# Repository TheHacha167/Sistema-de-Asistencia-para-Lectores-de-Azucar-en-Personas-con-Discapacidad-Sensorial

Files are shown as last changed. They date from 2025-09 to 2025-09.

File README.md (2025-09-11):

# TFG — Sistema de Asistencia para Lectores de Glucosa en Personas con Discapacidad Sensorial

Proyecto desarrollado como parte de mi **Trabajo Fin de Grado (TFG)**.  
**El proyecto ha sido bautizado como _Gluco Alert_.**  
El sistema detecta vibraciones anómalas en un lector de glucosa y notifica al cuidador mediante aviso local (luz y vibración) y remoto (llamadas/SMS).

---

## ÍNDICE

1. [Resumen](#1-resumen)  
2. [Características principales](#2-características-principales)  
3. [Hardware (BOM) y conexiones](#3-hardware-bom-y-conexiones)  
4. [Flujo de funcionamiento](#4-flujo-de-funcionamiento)  
5. [Control remoto (SMS / DTMF)](#5-control-remoto-sms--dtmf)  
6. [Compilación, flasheo y monitor](#6-compilación-flasheo-y-monitor)  
7. [Estructura de ficheros en la microSD](#7-estructura-de-ficheros-en-la-microsd)  
8. [Pruebas recomendadas](#8-pruebas-recomendadas)  
9. [Solución de problemas (Troubleshooting)](#9-solución-de-problemas-troubleshooting)  
10. [Seguridad eléctrica](#10-seguridad-eléctrica)  
11. [Licencia y citación](#11-licencia-y-citación)  
12. [Agradecimientos](#12-agradecimientos)  
13. [Vídeo de demostración (placeholder)](#13-vídeo-de-demostración-placeholder)  

---

## 1) RESUMEN

El sistema se basa en un **ESP32-C6** con firmware ESP-IDF y un módem GSM.  
Un sensor de vibración (salida digital) se procesa con antirruido (contador de ≥3 golpes en una ventana de 800 ms).  
Al dispararse la alerta, se activan tres relés (dos motores vibradores y una luz), se abre una ventana de atención de 30 s (botón físico), y si no se atiende, se realizan llamadas a números preconfigurados, reproduciendo un aviso por I2S desde la tarjeta microSD.  
Un pin de “armado” detecta la presencia del lector. Además, existe control remoto básico por SMS (con clave) y soporte DTMF en llamada.

---

## 2) CARACTERÍSTICAS PRINCIPALES

- Detección robusta de vibración con umbral configurable (≥3 en 800 ms).  
- Aviso local: dos motores vibradores + luz (a través de relés).  
- Ventana de atención: 30 s con botón físico (enciende luz de atención).  
- Llamadas automáticas a dos números, con reproducción de mensaje de voz por I2S/SD.  
- Entrada “ARM” para activar el sistema cuando el lector esté presente.  
- Control y diagnóstico por SMS (clave por defecto `0000`).  
- Prueba remota de sistema (activa relés durante 10 s, sin llamadas).  
- Diseño eléctrico con tres raíles: 5 V (lógica), 4,3 V (GSM), 12 V (motores).

---

## 3) HARDWARE (BOM) Y CONEXIONES

**Placa principal:**
- ESP32-C6-DevKitC-1

**Comunicación:**
- Módem GSM (SIM800/SIM8xx) alimentado a 4,3 V  
  (con >1000 µF cerca del VCC)

**Almacenamiento / audio:**
- Módulo microSD a 5 V (con regulador y adaptación de nivel)  
- DAC I2S integrado del ESP32-C6 (WAV mono 16-bit desde SD)

**Actuadores:**
- Módulo de 4 relés (LOW-trigger, se usan 3)  
- 2 motores vibradores (12 V conmutados por relé)  
- Luz / lamparita (red eléctrica conmutada por relé)

**Sensores y E/S locales:**
- Sensor de vibración Piezoeléctrico (salida digital, 5 V)  
- Entrada ARM  
- Botón de atención

**Alimentación:**
- 5 V → ESP32, módulo SD, módulo relés  
- 4,3 V → Módem GSM  
- 12 V → Motores vibradores  
- Condensadores: 1000 µF por raíl + 100 µF de desacoplo  
- Masa común en punto estrella cerca de GND del ESP32  
- Cableado corto para SPI y UART

**Pinout ESP32-C6:**

| Función | GPIO |
|---|---|
| Sensor vibración (D0) | GPIO2 |
| ARM | GPIO3 |
| Botón atención | GPIO4 |
| Relé Vib1 | GPIO8 |
| Relé Vib2 | GPIO10 |
| Relé Luz | GPIO11 |
| Relé reservado | GPIO12 |
| UART1 TX (SIM RX) | GPIO7 |
| UART1 RX (SIM TX) | GPIO6 |
| SD Card CS | GPIO5 |
| SD SCK | GPIO18 |
| SD MOSI | GPIO19 |
| SD MISO | GPIO21 |

**Notas:**
- PWRKEY del SIM a GND durante 1–2 s al encender  
- DTR a GND para evitar sleep  
- SPI: si es largo, reducir frecuencia a 4–10 MHz  
- Verificar niveles de MISO del módulo SD

---

## 4) FLUJO DE FUNCIONAMIENTO

1. **Arranque:** Inicialización de GPIO, SD, I2S, UART, timers  
2. **Lectura de ARM:** IDLE (ausente) / ARMED (presente)  
3. En estado ARMED:
   - Detección de ≥3 golpes → ALARM  
   - ALARM: activa vibradores y luz, inicia temporizador de 30 s  
   - Si se pulsa el botón: se atiende → relés OFF, colgado de módem  
   - Si NO se atiende: pasa a CALLING
4. **CALLING:**
   - Realiza llamadas a NUM1 y NUM2, reproduce mensaje por I2S/SD  
   - Vib OFF, luz queda ON  
   - Luego retorna a IDLE/ARMED según ARM

---

## 5) CONTROL REMOTO (SMS / DTMF)

**Por SMS (requiere clave, ej. `0000 prueba`)**

Comandos disponibles:
- Ayuda / menú  
- Prueba de relés (10 s)  
- Consulta de estado  
- Prueba de SMS/llamadas  
- Cancelar alerta  
- Reinicio del sistema  
- Cambio de clave

**Por DTMF (durante llamada):**
- Recepción de dígitos  
- Ejecución de acciones básicas con confirmación por audio  
- Archivos `/sdcard/0.wav` … `/sdcard/9.wav` opcionales

---

## 6) COMPILACIÓN, FLASHEO Y MONITOR

**Entorno recomendado:** PlatformIO + ESP-IDF (ESP32-C6)

```bash
# Compilar
pio run

# Flashear
pio run -t upload

# Monitor serie
pio device monitor -b 115200
```

**Configuración importante:**

- Velocidad del monitor: `115200` baudios
- Tamaño de la flash: debe coincidir con la configuración del módulo (ej. 2 MB si así está indicado en `sdkconfig` o `sdkconfig.defaults`)
- Mensajes del driver I2S tipo “legacy”: son normales, el sistema usa actualmente la API antigua y está pendiente de migrar a `i2s_std`

---

## 7) ESTRUCTURA DE FICHEROS EN LA MICROSD

- `/sdcard/ALERT.WAV` → mensaje de alerta que se reproduce durante las llamadas
- `/sdcard/0.WAV` a `/sdcard/9.WAV` → (opcional) locuciones o tonos DTMF para interacción en llamada

**Recomendaciones técnicas:**

- Formato: WAV PCM, 16-bit, mono, entre 8 y 16 kHz
- Nombres de archivos en mayúsculas
- Formato del sistema de archivos: FAT/FAT32

---

## 8) PRUEBAS RECOMENDADAS

Se recomienda realizar pruebas en las siguientes condiciones:

- Vibración real del lector de glucosa (simular golpes controlados)
- Verificación de la detección de ≥3 golpes en 800 ms
- Prueba de activación y cancelación con el botón físico
- Ensayo de ciclo completo: vibración → alerta → llamadas → reproducción de audio → vuelta a reposo
- Envío de comandos SMS (clave, prueba, consulta de estado)
- Prueba con diferentes niveles de batería / voltaje
- Control DTMF (si está habilitado)

---

## 9) SOLUCIÓN DE PROBLEMAS (TROUBLESHOOTING)

**SD Card:**

- Errores `0x107`, `0x108`, `0x109`:
  - Verifica alimentación 5 V y masa común
  - Chequea conexiones SPI (CS, SCK, MOSI, MISO)
  - Usa cableado corto
  - Reduce la frecuencia SPI (4–10 MHz)
  - Cambia la tarjeta por otra y reformatea en FAT

**Módem GSM:**

- No responde:
  - Alimentación de 4,3 V estable con picos de corriente disponibles
  - Condensador ≥1000 µF cerca del VCC
  - TX y RX correctamente conectados (no cruzados)
  - PWRKEY a GND 1–2 s al arrancar
  - Antena conectada, buena cobertura
  - SIM sin PIN activo

**Relés:**

- No activan:
  - Asegúrate de que el módulo es **LOW-trigger**
  - Si es **HIGH-trigger**, invierte la lógica en el firmware

**Vibración:**

- Falsos positivos:
  - Ajustar sensibilidad del sensor (potenciómetro)
  - Alimentar con 5 V estables
  - Separar el cableado de potencia de la señal
  - Evitar ruidos mecánicos cercanos

---

## 10) SEGURIDAD ELÉCTRICA

- Para cargas a 230 V:
  - Siempre conmutar la **fase (L)**, no el neutro (N)
  - Usar borneras, conectores y aislamientos apropiados
  - Mantener distancias de seguridad (fugas, aislamiento)
  - Instalar en caja cerrada sin partes accesibles a tensión de red
  - Revisión final por **personal cualificado**

---

## 11) LICENCIA Y CITACIÓN

Este proyecto se publica bajo la siguiente licencia:

**Creative Commons — Atribución-NoComercial-SinDerivadas 4.0 Internacional**  
[CC BY-NC-ND 4.0](https://creativecommons.org/licenses/by-nc-nd/4.0/deed.es)

- Puedes compartir el trabajo **citando al autor**
- No se permite el uso **comercial**
- No se permiten **obras derivadas**

---

## 13) VÍDEO DE DEMOSTRACIÓN (PLACEHOLDER)

Enlace al vídeo: **[pendiente de subir]**

---

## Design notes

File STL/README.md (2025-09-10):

# Glauco Alert — STL

Este directorio contiene los modelos 3D del proyecto **Glauco Alert** (carcasa, base, soportes y accesorios). Las piezas están pensadas para alojar un **lector FreeStyle Libre 2** de Abbott y los elementos mecánicos/electrónicos del sistema.

## Impresora y material
- **Impresora:** Artillery **Genius Pro**
- **Filamento:** PLA HD Winkle 1.75 mm **Malva** (1 kg)  
  <https://winkle.shop/producto/filamento-pla-hd-winkle-175-mm-1-kg-malva/>

> Si quieres replicar exactamente mi resultado, ese es el mismo filamento que utilicé.

## Perfil de impresión (Cura)
- **Perfil base:** Ajustes predeterminados de Cura para Genius Pro
- **Altura de capa:** **0.20 mm**
- **Infill:** **15%** patrón **Gyroid**
- **Soportes:** **Orgánicos** y **autogenerados** (solo donde haga falta)
- **Perímetros/Top/Bottom:** valores por defecto del perfil
- **Boquilla:** 0.4 mm (estándar)
- **Adhesión:** falda o balsa según necesidad de tu cama

> Los tiempos dependen de tu máquina y parámetros. A mí, imprimir **todo el conjunto** me llevó **aprox. 3 días** en total.

## Piezas incluidas (resumen)
- **Base** (módulos/apoyos)
- **Funda del lector**
- **Soporte del botón**
- **Soportes de motores de vibración** (x2 de cada uno)

> Las tolerancias están pensadas para PLA. Si tu impresora tiende a cerrar agujeros o encoger encajes, considera **ajustar flujo** o **escala ±1–2%**.

## Consejos de impresión
- Coloca las piezas **con la cara más plana hacia la cama** para minimizar soportes.
- Activa **árboles orgánicos** solo en salientes críticos (ahorra tiempo y material).
- Verifica **tolerancias en seco** antes de atornillar o montar electrónica.
- Para piezas de esfuerzo (soportes de motor), usa **más paredes** si lo ves necesario.

## Licencia
Estos modelos se publican bajo **CC BY-NC-ND 4.0**: puedes compartir citando al autor, **sin** uso comercial **ni** obras derivadas.

---
*Proyecto TFG — Glauco Alert.*

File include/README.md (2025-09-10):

Este directorio contiene los archivos de cabecera (header files) del proyecto. A continuación se describe el propósito de cada archivo y cómo configurar `secrets.h`.

## Archivos en este directorio

- **audio.h**  
  Declaraciones y definiciones relacionadas con el manejo de audio en el sistema.

- **dtmf.h**  
  Funciones y macros para el procesamiento de tonos DTMF (Dual-tone multi-frequency).

- **modem.h**  
  Interfaces y definiciones para la comunicación con el módem.

- **secrets.h**  
  Archivo destinado a almacenar información sensible como claves, tokens o contraseñas necesarias para el funcionamiento del sistema. Este archivo **no debe ser subido al repositorio** para proteger la información confidencial.

- **sms.h**  
  Declaraciones para el envío y recepción de mensajes SMS.

## Configuración de `secrets.h`

Para configurar `secrets.h`, crea el archivo si no existe y define en él las constantes o variables necesarias para tu entorno. Por ejemplo:

```c
// secrets.h (ejemplo)
#pragma once
#define NUM1 "1234567890"
#define NUM2 "0987654321"

```

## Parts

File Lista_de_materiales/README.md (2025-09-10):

# Lista de materiales (BOM) — Gluco Alert

Este documento recoge el *Bill of Materials* del proyecto **Glauco Alert** (TFG). Incluye los componentes principales, su función en el sistema y el motivo de elección, así como materiales recomendados adicionales para el montaje seguro y ordenado.

> **Nota:** La selección está orientada a un montaje doméstico con **ESP32‑C6 + módem GSM** y actuación por **relés** (motores de vibración y luz). Ajusta cantidades y referencias exactas según tu diseño final.

---

## 1) Componentes principales

| Componente | Modelo / referencia | Función en el sistema | Motivo de elección |
|---|---|---|---|
| **ESP32‑C6** | DevKitC‑1 (u otro compatible) | Unidad de procesamiento principal | MCU con Wi‑Fi/BLE/802.15.4; permite futura expansión (Zigbee/BLE). |
| **Módulo GSM** | **SIM800L / SIM8xx** con antena | Envío de **SMS** y **llamadas** de emergencia | Comunicación sin necesidad de internet. |
| **Módulo de relé (5 V, optoacoplado)**  | Placa de **1–4–8–16** canales | Activación de actuadores: **luces**, **vibradores** | Aislamiento para proteger el microcontrolador; fácil cableado de potencia. |
| **Motor de vibración DC** | 12 V, encapsulado | **Alerta física** (p. ej. bajo la almohada) | Robusto y fácil de accionar mediante relé a 12 V. |
| **Botón iluminado Ø60 mm** | Pulsador con LED integrado | **Atender / prueba / acción** manual | Alta visibilidad y fácil pulsación. |
| **Bloques de terminales** | **KF301** (2P–4P) | Conexión de alimentación y actuadores | Conector de tornillo fiable y fácil de montar/desmontar. |
| **Kit pines 2.54 mm** | Macho/hembra, tiras rompibles | Interconexión y soldadura en placas | Compatible con perfboard/prototipado. |
| **Conectores JST** | JST‑XH/JST‑PH (2–5 pines, según uso) | Conexiones limpias entre módulos | Útiles para alimentación y sensores; evitan falsos contactos. |
| **Conectores GX12/GX16/GX20** | Circulares metálicos con bloqueo (≥4 pines) | Conexiones externas resistentes | Cuerpo metálico con rosca; conexión segura. |
| **Fuente de alimentación** | 12 V para motores; **USB‑C PD** / 5 V para electrónica| Proveer energía a cada raíl | Dimensionar según consumo total; separa potencia (12 V) de lógica (5 V). |
| **Regulador buck DC‑DC** | **LM2596** (hasta 3 A) | Adaptar tensiones de entrada a 5 V / 4.3 V (GSM) | Eficiente; protege frente a sobre/infra‑tensión si se ajusta correctamente. |
| **Tornillería M3** | Tornillos **DIN912** + tuercas de **inserción** | Ensamblaje en carcasa impresa | Compatibles con diseño mecánico (Fusion 360); montaje sólido. |
| **Imanes de neodimio** | Circulares, alta potencia | Anclaje de funda al cuerpo principal | Opcional según diseño físico. |
| **Conectores pogo magnéticos** | Pines de resorte + base magnética | Pruebas/módulos fácilmente desconectables | Conexión rápida y segura en piezas móviles. |
| **Impresora 3D** | **Artillery Genius Pro** | Fabricación de carcasa y soportes | Impresión precisa; cama caliente; extrusor directo. |
| **Filamento PLA** | **Winkle PLA HD 1.75 mm (Malva, 1 kg)** | Material de la carcasa | Buena tolerancia dimensional y acabado; fácil de imprimir. |

---

## 2) Materiales recomendados adicionales

- **Termorretráctil** (varios diámetros): aislamiento y alivio de tensiones en uniones.
- **Cableado para red eléctrica 230 V**: **1.5 mm²** (≈ **AWG 15/16**) con manguera de 2/3 conductores según norma local; **conductor de tierra** si procede.
- **Cableado de señal**: 22–24 AWG multihilo para UART/SPI/SEÑALES de baja corriente.
- **Standoffs / separadores**: **plástico** (nylon) preferible a bronce para evitar cortos.
- **Bridas y anclajes adhesivos**: guiado de mazos y descarga de tracción.
- **Cinta Kapton / Doble cara**: fijación térmica y sujeción ligera.
- **Malla desoldadora (solder wick)** y **bomba de desoldar**: retrabajos limpios.
- **Estaño con flux** (Sn60Pb40 o SAC lead‑free) y **flux** adicional (no‑clean).
- **Multímetro** y **comprobador de continuidad**; opcional **analizador lógico** para SPI/UART.

> **Seguridad:** Toda la parte a **230 V** debe respetar normativa local (distancias, aislamiento, puesta a tierra, envolvente). Si hay dudas, que lo revise un técnico cualificado.

---

## 3) Notas de integración

- **Raíles de alimentación** recomendados: **12 V** (motores), **5 V** (lógica/relés), **4.3 V** (GSM). Masas unidas cerca del ESP32‑C6.
- **SD a 5 V** con regulador/adaptación de niveles habituales; **SPI** con cableado corto y, si hace falta, bajar frecuencia (4–10 MHz).
- **UART GSM** (SIM800L): TX/RX cruzados; **condensador ≥1000 µF** cerca de VBAT; PWRKEY a GND 1–2 s en arranque.
- **Relés**: si son **LOW‑trigger**, verificar lógica en firmware; considerar **snubber RC/TVS** en motores a 12 V.

---

## 4) Referencias de impresión 3D (resumen)

- **Impresora:** Artillery Genius Pro  
- **Material:** Winkle PLA HD 1.75 mm (Malva) — [enlace del fabricante](https://winkle.shop/producto/filamento-pla-hd-winkle-175-mm-1-kg-malva/)  
- **Cura:** capa **0.20 mm**, infill **gyroid 15%**, soportes **orgánicos** y **autogenerados**.

---

> *Tabla 4. Hardware usado.*  
> Proyecto: **Glauco Alert — Sistema de Asistencia para Lectores de Azúcar en Personas con Discapacidad Sensorial (TFG)**.  
> Licencia: **CC BY‑NC‑ND 4.0**.

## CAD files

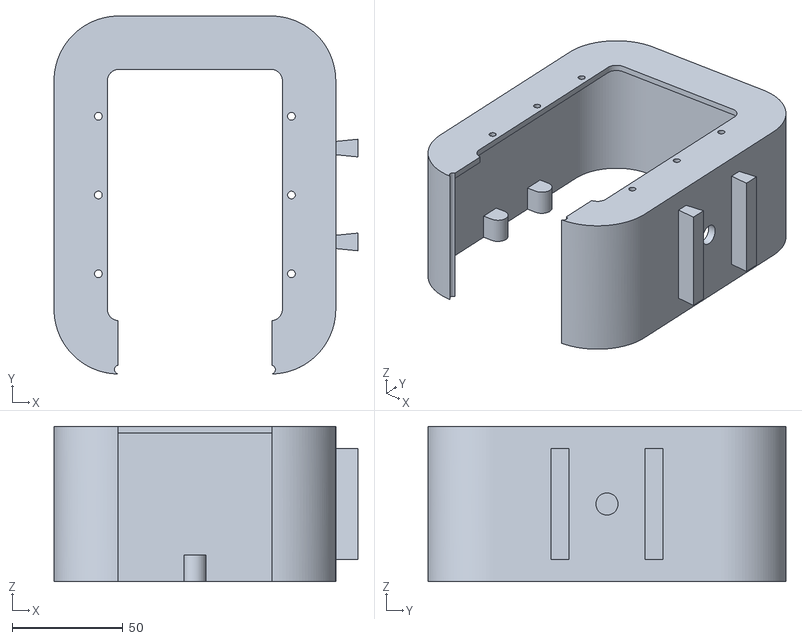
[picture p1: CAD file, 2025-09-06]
STL/Base/Base_2.stl
137.0 x 161.4 x 70.0

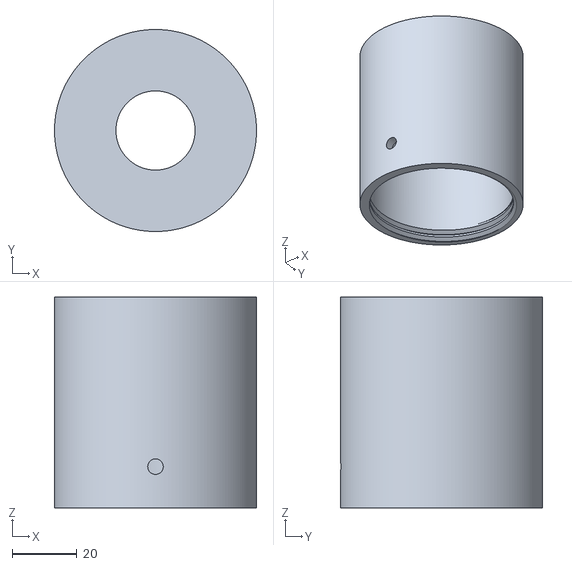
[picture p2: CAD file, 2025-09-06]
STL/Botón/Boton_1.stl
62.3 x 62.3 x 65.0

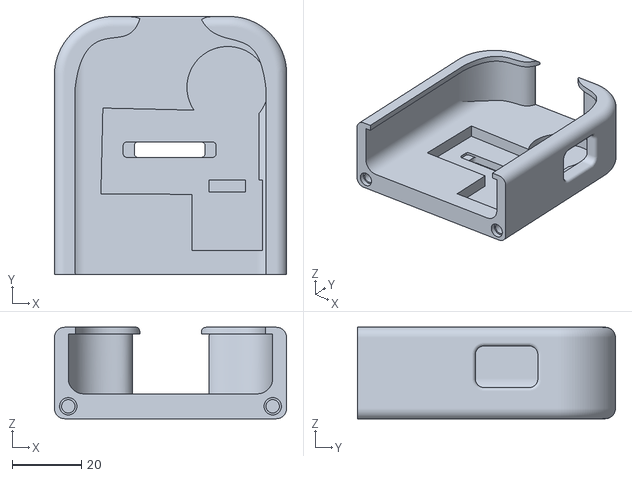
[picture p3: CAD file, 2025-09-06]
STL/Funda_Lector/Funda_lector_1.stl
67.0 x 74.4 x 26.4

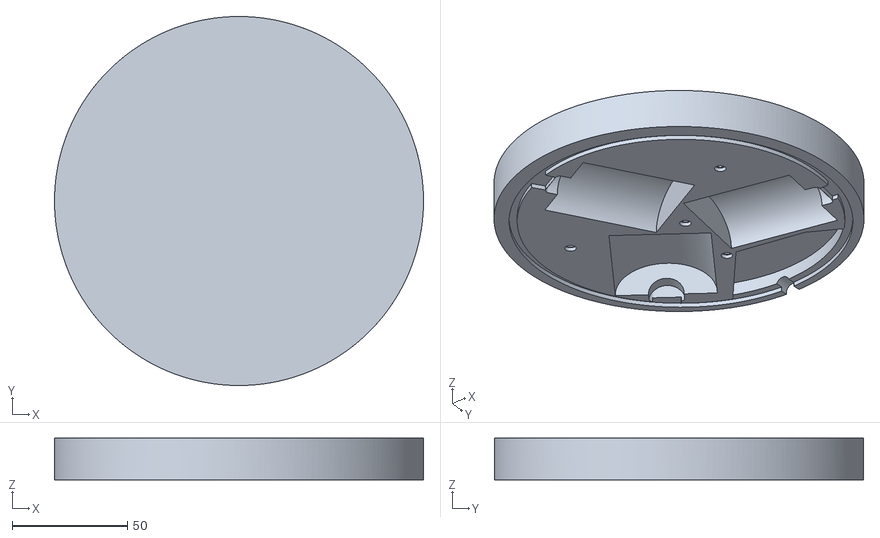
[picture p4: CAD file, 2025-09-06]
STL/Funda_motores/Funda_motores_1.stl
160.0 x 160.0 x 18.0

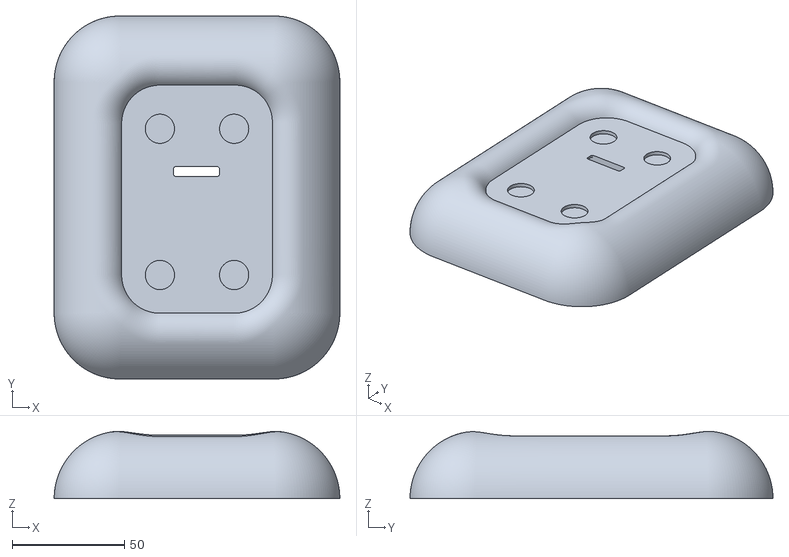
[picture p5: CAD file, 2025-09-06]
STL/Base/Base_1.stl
127.0 x 161.4 x 29.9

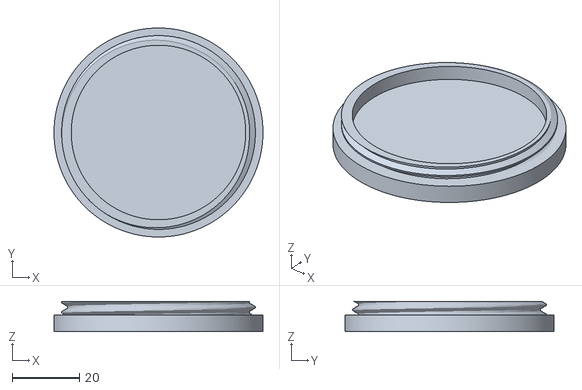
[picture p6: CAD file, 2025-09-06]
STL/Botón/Boton_2.stl
62.3 x 62.3 x 9.00

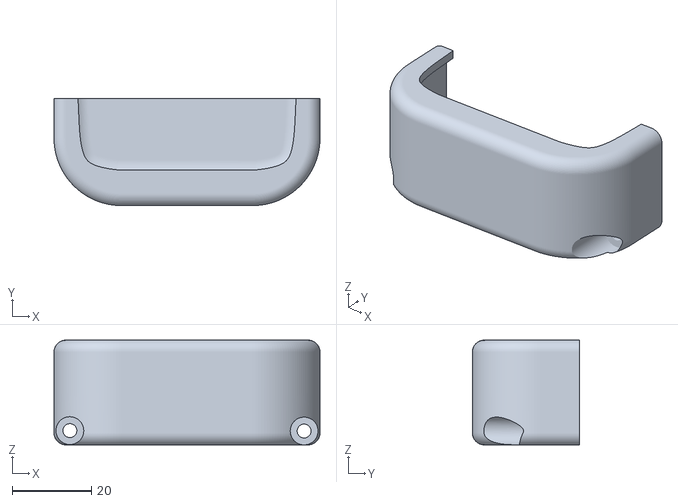
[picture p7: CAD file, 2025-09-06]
STL/Funda_Lector/Funda_lector_2.stl
67.0 x 27.0 x 26.4

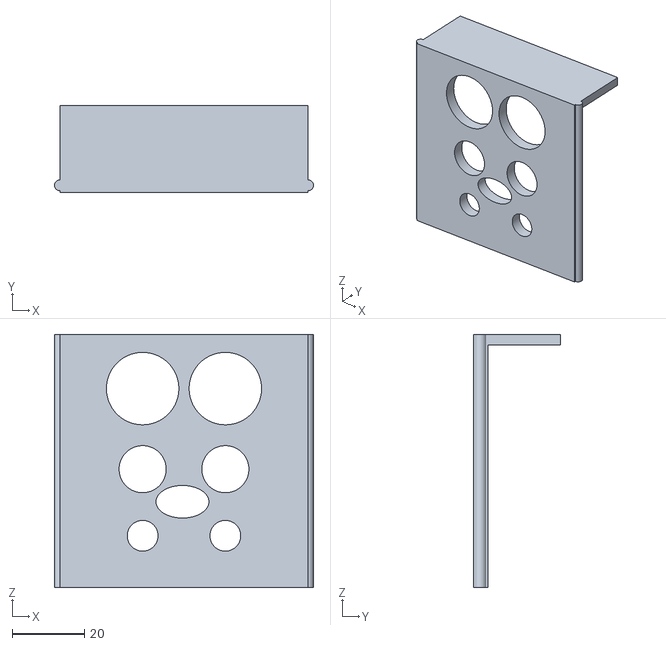
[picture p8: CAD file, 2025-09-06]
STL/Base/Base_3.stl
71.5 x 24.0 x 70.0

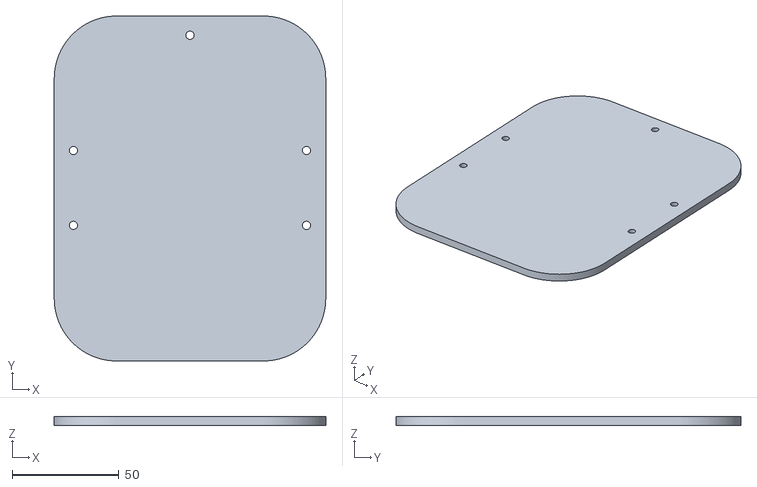
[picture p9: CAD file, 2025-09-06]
STL/Base/Base_4.stl
127.0 x 161.4 x 4.00

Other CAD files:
STL/Funda_motores/Funda_motores_2.stl

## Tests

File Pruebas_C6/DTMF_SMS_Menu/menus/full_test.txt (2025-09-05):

Iniciando prueba completa del sistema. Espere confirmación.

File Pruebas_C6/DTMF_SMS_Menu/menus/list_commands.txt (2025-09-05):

Listado de comandos enviados por SMS al número de llamada.

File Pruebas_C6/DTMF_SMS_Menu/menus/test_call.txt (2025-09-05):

Realizando prueba de llamada. Esto colgará automáticamente

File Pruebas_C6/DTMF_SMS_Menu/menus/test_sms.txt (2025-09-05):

Enviando SMS de prueba. Comprueba tu bandeja de entrada

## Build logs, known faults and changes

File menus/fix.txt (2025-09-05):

ffmpeg -i menu.wav -ar 16000 -ac 1 -sample_fmt s16 menu_fixed.wav

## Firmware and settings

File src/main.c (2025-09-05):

#include <stdio.h>
#include <string.h>
#include <stdint.h>
#include "freertos/FreeRTOS.h"
#include "freertos/task.h"
#include "freertos/timers.h"
#include "driver/gpio.h"
#include "driver/uart.h"
#include "driver/i2s.h"   
#include "esp_log.h"
#include "esp_err.h"

#include "audio.h"
#include "modem.h"
#include "secrets.h"

// ==================== PINES / CONFIG ====================
static const char *ALERT_TAG = "ALERT";
static const char *MAIN_TAG  = "MAIN";

// Sensor vibración
#define PIN_VIB_SENSOR    GPIO_NUM_2    // D0 sensor (activo alto)

// *** Mapeo final relés ***
#define PIN_RELAY_VIB1    GPIO_NUM_8    // Vibrador 1
#define PIN_RELAY_VIB2    GPIO_NUM_10   // Vibrador 2
#define PIN_RELAY_LIGHT   GPIO_NUM_11   // Lamparita (luz)

// Futuro relé (reservado) 
#define PIN_RELAY_EXTRA   GPIO_NUM_12

// Otros pines
#define PIN_BTN_RESET     GPIO_NUM_4    // botón (pull-up, activo a GND)
#define PIN_ARM_SENSE     GPIO_NUM_3    // lector puentea a GND (activo-bajo)

// Lógicas
#define RELAY_ACTIVE_HIGH_DEFAULT  0    // 0 = activo-bajo (LOW=ON), 1 = activo-alto
#define SENSOR_ACTIVE_HIGH         1
#define BTN_ACTIVE_LOW             1
#define ARM_ACTIVE_WHEN_HIGH       0

// Antirruido del sensor
#define VIB_WINDOW_MS           800
#define VIB_THRESHOLD           3

// Tiempos
#define ATTEND_TIMEOUT_MS       30000
#define CALL_PLAY_MS            12000
#define LAMP_ON_MS              30000

// Módem (UART1)
#define MODEM_TX_PIN  GPIO_NUM_6
 
#define MODEM_BAUD    115200
const uart_port_t MODEM_UART = UART_NUM_1;

// I2S (audio.h usa legacy)
#ifndef I2S_NUM
#define I2S_NUM I2S_NUM_0
#endif

// ==================== ESTADO / GLOBALES ====================
typedef enum { ST_IDLE=0, ST_ARMED, ST_ALARM, ST_CALLING } alert_state_t;
static volatile alert_state_t g_state = ST_IDLE;

static TimerHandle_t g_timer_alarm      = NULL;
static TimerHandle_t g_timer_lamp       = NULL;
static TimerHandle_t g_timer_vib_window = NULL;
static TimerHandle_t g_timer_test       = NULL;

static volatile uint16_t g_vib_count = 0;
static volatile bool g_test_active   = false;

// Polaridad runtime (0=activo-bajo, 1=activo-alto)
static volatile int g_relay_active_high = RELAY_ACTIVE_HIGH_DEFAULT;

// ==================== PROTOTIPOS NECESARIOS (callbacks y exports) ====================
static void vTimerVibWindowTimeout(TimerHandle_t xTimer);
static void vTimerAlarmTimeout(TimerHandle_t xTimer);
static void vTimerLampTimeout(TimerHandle_t xTimer);
static void vTimerTestTimeout(TimerHandle_t xTimer);

// Exportadas para SMS (8/41/42/43/44/90/91)
void alert_test_start(uint32_t ms);
void relays_force_for_ms(bool vib1, bool vib2, bool lamp, uint32_t ms);
void set_relay_polarity(int active_high);
int  get_relay_polarity(void) { return g_relay_active_high; }

// Módem / audio
void      modem_task(void *arg);
esp_err_t modem_init(void);
esp_err_t modem_dial(const char *number);
void      modem_hangup(void);
void      audio_play_wav(const char *path);

// ==================== HELPERS GPIO ====================
static inline void relay_write(gpio_num_t pin, bool on) {
    int level = g_relay_active_high ? (on ? 1 : 0) : (on ? 0 : 1);
    gpio_set_level(pin, level);
}
static inline void relays_set(bool vib1, bool vib2, bool lamp) {
    relay_write(PIN_RELAY_VIB1, vib1);
    relay_write(PIN_RELAY_VIB2, vib2);
    relay_write(PIN_RELAY_LIGHT, lamp);
}
static inline void lamp_set(bool on) { relay_write(PIN_RELAY_LIGHT, on); }

static inline bool read_sensor_active(void) {
    int v = gpio_get_level(PIN_VIB_SENSOR);
    return SENSOR_ACTIVE_HIGH ? (v==1) : (v==0);
}
static inline bool read_button_pressed(void) {
    int v = gpio_get_level(PIN_BTN_RESET);
    return BTN_ACTIVE_LOW ? (v==0) : (v==1);
}
static inline bool read_arm_present(void) {
    int v = gpio_get_level(PIN_ARM_SENSE);
    return ARM_ACTIVE_WHEN_HIGH ? (v==1) : (v==0);
}

// ==================== ESTADOS ====================
static void enter_idle(void) {
    g_state = ST_IDLE;
    if (g_timer_alarm) xTimerStop(g_timer_alarm, 0);
    if (!g_test_active) relays_set(false,false,false);
    ESP_LOGI(ALERT_TAG, "Estado: IDLE (lector ausente)");
}
static void enter_armed(void) {
    g_state = ST_ARMED;
    if (g_timer_alarm) xTimerStop(g_timer_alarm, 0);
    if (!g_test_active) relays_set(false,false,false);
    ESP_LOGI(ALERT_TAG, "Estado: ARMED (lector presente)");
}

// ==================== TIMERS ====================
static void vTimerVibWindowTimeout(TimerHandle_t xTimer) {
    g_vib_count = 0;
}
static void vTimerAlarmTimeout(TimerHandle_t xTimer) {
    if (g_state != ST_ALARM) return;
    ESP_LOGW(ALERT_TAG, "No atendida en 30s → llamadas");
    g_state = ST_CALLING;

    const char *numbers[] = { NUM1, NUM2 };
    for (int i=0; i<2; i++) {
        ESP_LOGI(ALERT_TAG, "Llamando a %s …", numbers[i]);
        if (modem_dial(numbers[i]) == ESP_OK) {
            vTaskDelay(pdMS_TO_TICKS(2500));
            audio_play_wav("/sdcard/alert.wav");
            vTaskDelay(pdMS_TO_TICKS(CALL_PLAY_MS));
            modem_hangup();
        }
        vTaskDelay(pdMS_TO_TICKS(800));
    }
    relays_set(false,false,true);  // vib OFF, lámpara ON fija
}
static void vTimerLampTimeout(TimerHandle_t xTimer) {
    lamp_set(false);
    ESP_LOGI(ALERT_TAG, "Lamparita OFF (timeout)");
}
static void vTimerTestTimeout(TimerHandle_t xTimer) {
    g_test_active = false;
    relays_set(false,false,false);
    ESP_LOGI(ALERT_TAG, "TEST/FORCE: FIN (relés OFF)");
}

// ==================== ISR ====================
static void IRAM_ATTR isr_btn(void *arg) {
    if (g_test_active) { // cancelar test/forzado si estaba activo
        BaseType_t hpw2 = pdFALSE;
        relays_set(false,false,false);
        if (g_timer_test) xTimerStopFromISR(g_timer_test, &hpw2);
        g_test_active = false;
        if (hpw2) portYIELD_FROM_ISR();
    }
    if (read_button_pressed()) {
        BaseType_t hpw = pdFALSE;
        lamp_set(true);
        if (g_timer_lamp) {
            xTimerStopFromISR(g_timer_lamp, &hpw);
            xTimerStartFromISR(g_timer_lamp, &hpw);
        }
        if (g_state == ST_ALARM || g_state == ST_CALLING) {
            relays_set(false,false,false);
            if (g_timer_alarm) xTimerStopFromISR(g_timer_alarm, &hpw);
            modem_hangup();
            g_state = read_arm_present() ? ST_ARMED : ST_IDLE;
            ESP_EARLY_LOGI(ALERT_TAG, "Atendido por botón. Lámpara ON %d ms.", LAMP_ON_MS);
        }
        if (hpw) portYIELD_FROM_ISR();
    }
}

static void IRAM_ATTR isr_sensor(void *arg) {
    if (g_test_active) return; // ignora durante test/forzado
    if (g_state == ST_ARMED && read_arm_present()) {
        uint16_t c = ++g_vib_count;
        BaseType_t hpw = pdFALSE;
        if (g_timer_vib_window) {
            xTimerStopFromISR(g_timer_vib_window, &hpw);
            xTimerStartFromISR(g_timer_vib_window, &hpw);
        }
        if (c >= VIB_THRESHOLD) {
            g_vib_count = 0;
            if (g_timer_vib_window) xTimerStopFromISR(g_timer_vib_window, &hpw);
            g_state = ST_ALARM;
            relays_set(true,true,true);
            if (g_timer_alarm) {
                xTimerStopFromISR(g_timer_alarm, &hpw);
                xTimerStartFromISR(g_timer_alarm, &hpw);
            }
            ESP_EARLY_LOGE(ALERT_TAG, "ALERTA: %d vibraciones en %d ms",
                           VIB_THRESHOLD, VIB_WINDOW_MS);
        }
        if (hpw) portYIELD_FROM_ISR();
    }
}

// ==================== TAREAS ====================
static void arm_monitor_task(void *arg) {
    bool prev = read_arm_present();
    ESP_LOGI(ALERT_TAG, "ARM monitor: start, present=%s", prev ? "YES" : "NO");
    for (;;) {
        if (g_test_active) { vTaskDelay(pdMS_TO_TICKS(50)); continue; }
        vTaskDelay(pdMS_TO_TICKS(100));
        bool now = read_arm_present();
        if (now != prev) {
            if (now) enter_armed(); else enter_idle();
            prev = now;
        }
    }
}

// ==================== INIT ====================
static void alert_system_start(void) {
    gpio_install_isr_service(0);

    // Salidas (3 relés) + extra reservado comentado
    gpio_config_t outcfg = {
        .pin_bit_mask = (1ULL<<PIN_RELAY_VIB1)|
                        (1ULL<<PIN_RELAY_VIB2)|
                        (1ULL<<PIN_RELAY_LIGHT)
                        /* | (1ULL<<PIN_RELAY_EXTRA) */,
        .mode = GPIO_MODE_OUTPUT
    };
    gpio_config(&outcfg);
    relays_set(false,false,false);

    // Sensor vibración (PULL-DOWN para que no flote si no está)
    gpio_config_t incfg = {
        .pin_bit_mask = (1ULL<<PIN_VIB_SENSOR),
        .mode = GPIO_MODE_INPUT,
        .pull_up_en   = SENSOR_ACTIVE_HIGH ? GPIO_PULLUP_DISABLE  : GPIO_PULLUP_ENABLE,
        .pull_down_en = SENSOR_ACTIVE_HIGH ? GPIO_PULLDOWN_ENABLE : GPIO_PULLDOWN_DISABLE,
        .intr_type    = SENSOR_ACTIVE_HIGH ? GPIO_INTR_POSEDGE    : GPIO_INTR_NEGEDGE
    };
    gpio_config(&incfg);
    gpio_isr_handler_add(PIN_VIB_SENSOR, isr_sensor, NULL);

    // Botón
    gpio_config_t btncfg = {
        .pin_bit_mask = (1ULL<<PIN_BTN_RESET),
        .mode = GPIO_MODE_INPUT,
        .pull_up_en   = BTN_ACTIVE_LOW ? GPIO_PULLUP_ENABLE  : GPIO_PULLUP_DISABLE,
        .pull_down_en = BTN_ACTIVE_LOW ? GPIO_PULLDOWN_DISABLE : GPIO_PULLDOWN_ENABLE,
        .intr_type    = BTN_ACTIVE_LOW ? GPIO_INTR_NEGEDGE   : GPIO_INTR_POSEDGE
    };
    gpio_config(&btncfg);
    gpio_isr_handler_add(PIN_BTN_RESET, isr_btn, NULL);

    // ARM (lector a GND)
    gpio_config_t armcfg = {
        .pin_bit_mask = (1ULL<<PIN_ARM_SENSE),
        .mode = GPIO_MODE_INPUT,
        .pull_up_en   = GPIO_PULLUP_ENABLE,
        .pull_down_en = GPIO_PULLDOWN_DISABLE,
        .intr_type    = GPIO_INTR_DISABLE
    };
    gpio_config(&armcfg);

    // Timers
    g_timer_alarm      = xTimerCreate("attend_tmo", pdMS_TO_TICKS(ATTEND_TIMEOUT_MS), pdFALSE, NULL, vTimerAlarmTimeout);
    g_timer_lamp       = xTimerCreate("lamp_tmo",   pdMS_TO_TICKS(LAMP_ON_MS),       pdFALSE, NULL, vTimerLampTimeout);
    g_timer_vib_window = xTimerCreate("vib_win",    pdMS_TO_TICKS(VIB_WINDOW_MS),    pdFALSE, NULL, vTimerVibWindowTimeout);
    if (!g_timer_test)
        g_timer_test   = xTimerCreate("test_tmo",   pdMS_TO_TICKS(10000),            pdFALSE, NULL, vTimerTestTimeout);

    if (read_arm_present()) enter_armed(); else enter_idle();
    xTaskCreate(arm_monitor_task, "arm_monitor", 2048, NULL, 5, NULL);

    ESP_LOGI(ALERT_TAG, "Sistema de alerta listo.");
}

// ==================== AUDIO ====================
void audio_play_wav(const char *path)
{
    FILE *f = fopen(path, "rb");
    if (!f) { ESP_LOGE("AUDIO", "No puedo abrir %s", path); return; }
    fseek(f, 44, SEEK_SET); // cabecera WAV
    uint8_t buf[1024];
    size_t rd, wr;
    while ((rd = fread(buf, 1, sizeof buf, f)) > 0) {
        i2s_write(I2S_NUM, buf, rd, &wr, portMAX_DELAY);
    }
    fclose(f);
}

// ==================== MÓDEM ====================
esp_err_t modem_init(void)
{
    uart_config_t ucfg = {
        .baud_rate = MODEM_BAUD,
        .data_bits = UART_DATA_8_BITS,
        .parity    = UART_PARITY_DISABLE,
        .stop_bits = UART_STOP_BITS_1,
        .flow_ctrl = UART_HW_FLOWCTRL_DISABLE,
        #if defined(UART_SCLK_DEFAULT)
            .source_clk = UART_SCLK_DEFAULT
        #elif defined(UART_SCLK_APB)
            .source_clk = UART_SCLK_APB
        #else
            .source_clk = UART_SCLK_RTC
        #endif
    };
    ESP_ERROR_CHECK(uart_param_config(MODEM_UART, &ucfg));
    ESP_ERROR_CHECK(uart_set_pin(MODEM_UART, MODEM_TX_PIN, MODEM_RX_PIN,
                                 UART_PIN_NO_CHANGE, UART_PIN_NO_CHANGE));
    ESP_ERROR_CHECK(uart_driver_install(MODEM_UART, 1024, 0, 0, NULL, 0));

    if (xTaskCreate(modem_task, "modem_task", 12288, NULL, 5, NULL) != pdPASS) {
        ESP_LOGE("MODEM", "No pude crear modem_task");
        return ESP_FAIL;
    }
    ESP_LOGI(MAIN_TAG, "UART del módem listo a %d baudios", MODEM_BAUD);
    return ESP_OK;
}

esp_err_t modem_dial(const char *number)
{
    if (!number || !*number) return ESP_ERR_INVALID_ARG;
    char cmd[48];
    int n = snprintf(cmd, sizeof cmd, "ATD%s;\r", number);
    if (n <= 0 || n >= (int)sizeof cmd) return ESP_ERR_INVALID_ARG;
    uart_write_bytes(MODEM_UART, cmd, n);
    return ESP_OK;
}

void modem_hangup(void)
{
    static const char *cmd = "ATH\r";
    uart_write_bytes(MODEM_UART, cmd, 4);
}

// ==================== PRUEBAS / FORZADOS (para SMS) ====================
void alert_test_start(uint32_t ms) {
    g_test_active = true;
    relays_set(true,true,true);  // ON continuo durante 'ms'
    if (!g_timer_test) g_timer_test = xTimerCreate("test_tmo", pdMS_TO_TICKS(ms), pdFALSE, NULL, vTimerTestTimeout);
    xTimerStop(g_timer_test, 0);
    xTimerChangePeriod(g_timer_test, pdMS_TO_TICKS(ms), 0);
    xTimerStart(g_timer_test, 0);
    ESP_LOGI(ALERT_TAG, "TEST: relés ON por %u ms (sin llamadas)", (unsigned)ms);
}

void relays_force_for_ms(bool vib1, bool vib2, bool lamp, uint32_t ms) {
    g_test_active = true;
    relays_set(vib1, vib2, lamp);
    if (!g_timer_test) g_timer_test = xTimerCreate("test_tmo", pdMS_TO_TICKS(ms), pdFALSE, NULL, vTimerTestTimeout);
    xTimerStop(g_timer_test, 0);
    xTimerChangePeriod(g_timer_test, pdMS_TO_TICKS(ms), 0);
    xTimerStart(g_timer_test, 0);
    ESP_LOGI(ALERT_TAG, "FORCE: v1=%d v2=%d lamp=%d por %u ms",
             (int)vib1, (int)vib2, (int)lamp, (unsigned)ms);
}

void set_relay_polarity(int active_high) {
    g_relay_active_high = active_high ? 1 : 0;
    ESP_LOGW(ALERT_TAG, "Polaridad relés: %s",
             g_relay_active_high ? "ACTIVO-ALTO (HIGH=ON)" : "ACTIVO-BAJO (LOW=ON)");
}

// ==================== MAIN ====================
void app_main(void) {
    audio_init();          // I2S + SD
    (void)dtmf_files;      // silenciar warning unused
    modem_init();          // UART + modem_task
    alert_system_start();  // lógica de alerta

    ESP_LOGI(MAIN_TAG, "Sistema iniciado.");
    for (;;) vTaskDelay(pdMS_TO_TICKS(1000));
}

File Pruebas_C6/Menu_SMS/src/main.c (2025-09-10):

#include <string.h>
#include <stdlib.h>
#include <stdbool.h>
#include "freertos/FreeRTOS.h"
#include "freertos/task.h"
#include "driver/uart.h"
#include "esp_log.h"
#include "secrets.h"
#include "esp_timer.h"


static const char *TAG = "SIM800";
#define MODEM_UART   UART_NUM_1
#define MODEM_TX_PIN 6
#define MODEM_RX_PIN 7
#define MODEM_BAUD   115200
#define UART_BUF     512
static char current_key[16] = "0000";


static void uart_init(void) {
    uart_config_t cfg = {
        .baud_rate = MODEM_BAUD,
        .data_bits = UART_DATA_8_BITS,
        .parity    = UART_PARITY_DISABLE,
        .stop_bits = UART_STOP_BITS_1,
        .flow_ctrl = UART_HW_FLOWCTRL_DISABLE,
        .source_clk= UART_SCLK_DEFAULT,
    };
    ESP_ERROR_CHECK(uart_driver_install(MODEM_UART, UART_BUF, UART_BUF, 0, NULL, 0));
    ESP_ERROR_CHECK(uart_param_config(MODEM_UART, &cfg));
    ESP_ERROR_CHECK(uart_set_pin(MODEM_UART, MODEM_TX_PIN, MODEM_RX_PIN, UART_PIN_NO_CHANGE, UART_PIN_NO_CHANGE));
    ESP_LOGI(TAG, "UART inicializada para SIM800L");
}

static void at_send(const char *cmd) {
    ESP_LOGI(TAG, "AT> %s", cmd);
    uart_write_bytes(MODEM_UART, cmd, strlen(cmd));
    uart_write_bytes(MODEM_UART, "\r", 1);
    vTaskDelay(pdMS_TO_TICKS(200));
}

static void send_sms(const char *num, const char *txt) {
    char cmd[64];
    at_send("AT+CMGF=1");
    snprintf(cmd, sizeof(cmd), "AT+CMGS=\"%s\"", num);
    at_send(cmd);
    // esperar el prompt '>'
    char c;
    while (uart_read_bytes(MODEM_UART, (uint8_t*)&c, 1, pdMS_TO_TICKS(500)) > 0) {
        if (c == '>') break;
    }
    uart_write_bytes(MODEM_UART, txt, strlen(txt));
    uart_write_bytes(MODEM_UART, "\x1A", 1);
    ESP_LOGI(TAG, "SMS enviado a %s", num);
    vTaskDelay(pdMS_TO_TICKS(1000));
}

static bool remitente_valido(const char *from) {
    return strstr(from, NUM1) || strstr(from, NUM2);
}


static void procesar_sms(const char *msg, const char *from) {
    // 1) Validar remitente
    if (!remitente_valido(from)) {
        ESP_LOGW(TAG, "Remitente no autorizado: %s", from);
        return;
    }
    // 2) Validar clave
    size_t key_len = strlen(current_key);
    if (strncmp(msg, current_key, key_len) != 0) {
        ESP_LOGW(TAG, "Clave inválida: %.*s", (int)key_len, msg);
        return;
    }
    // 3) Extraer el número de comando
    const char *p = msg + key_len;
    while (*p == ' ') p++;  // saltar espacios
    int cmd = atoi(p);

    // 4) Preparar respuesta
    char resp[256] = {0};

    switch (cmd) {
        case 1:
            snprintf(resp, sizeof(resp),
                "1: Listar comandos\n"
                "2: Cambiar clave\n"
                "3: Mostrar alertas\n"
                "4: Probar llamadas\n"
                "5: Probar SMS\n"
                "6: Cancelar alerta\n"
                "7: Reiniciar dispositivo\n"
                "8: Prueba sistema\n"
                "9: Estado del sistema");
            break;

        case 2: {
            // Cambiar clave: por ejemplo "0000 1234"
            const char *nueva = strchr(p, ' ');
            if (nueva && strlen(nueva + 1) < sizeof(current_key)) {
                strcpy(current_key, nueva + 1);
                snprintf(resp, sizeof(resp), "Clave cambiada a '%s'", current_key);
            } else {
                snprintf(resp, sizeof(resp),
                         "Uso: %s 2 <nueva_clave>", current_key);
            }
            break;
        }

        case 3:
            // Aquí tu lógica de alertas
            snprintf(resp, sizeof(resp), "Alertas: ninguna");
            break;

        case 4:
            // Llamada de prueba
            // test_calls();
            snprintf(resp, sizeof(resp), "Probando llamadas...");
            break;

        case 5:
            // SMS de prueba
            send_sms(from, "SMS de prueba OK");
            return;

        case 6:
            // Cancelar alerta
            // cancel_alert();
            snprintf(resp, sizeof(resp), "Alerta cancelada");
            break;

        case 7:
            // Reiniciar dispositivo
            send_sms(from, "Reiniciando dispositivo...");
            vTaskDelay(pdMS_TO_TICKS(500));
            esp_restart();
            return;

        case 8:
            // Prueba general del sistema
            snprintf(resp, sizeof(resp), "Prueba del sistema OK");
            break;

        case 9:
            // Estado del sistema (uptime en segundos)
            snprintf(resp, sizeof(resp),
                     "Tiempo activo: %lld s",
                     (long long)esp_timer_get_time() / 1000000);
            break;

        default:
            snprintf(resp, sizeof(resp),
                     "Comando desconocido. Envía '1' para ayuda.");
            break;
    }

    // 5) Enviar respuesta final
    send_sms(from, resp);
}

static void read_sms(int index) {
    char cmd[32];
    snprintf(cmd, sizeof(cmd), "AT+CMGR=%d", index);
    at_send(cmd);
    vTaskDelay(pdMS_TO_TICKS(500));
    char buf[UART_BUF*2] = {0};
    int len, pos = 0;
    // leer toda la respuesta
    while ((len = uart_read_bytes(MODEM_UART, (uint8_t*)buf + pos, sizeof(buf)-pos-1, pdMS_TO_TICKS(200))) > 0) {
        pos += len;
    }
    buf[pos] = '\0';
    ESP_LOGI(TAG, "CMGR>> %s", buf);
    // parse +CMGR: "mem","num",...\r\nmessage\r\n
    char from[32] = {0};
    char *p = strstr(buf, "+CMGR:");
    if (p) {
        // encontrar segundo grupo de comillas que es el número
        // skip +CMGR:
        p = strchr(p, '"'); if (!p) return;
        p = strchr(p+1, '"'); if (!p) return;
        p = strchr(p+1, '"'); if (!p) return;
        char *q = strchr(p+1, '"'); if (!q) return;
        int nlen = q - (p+1);
        if (nlen > (int)sizeof(from)-1) nlen = sizeof(from)-1;
        memcpy(from, p+1, nlen); from[nlen] = '\0';
        // el mensaje comienza después de CRLF
        char *msg = strstr(q+1, "\r\n");
        if (msg) {
            msg += 2;
            char *e = strstr(msg, "\r\n"); if (e) *e = '\0';
            ESP_LOGI(TAG, "SMS de %s: %s", from, msg);
            procesar_sms(msg, from);
        }
    }
    // borrar SMS
    snprintf(cmd, sizeof(cmd), "AT+CMGD=%d", index);
    at_send(cmd);
}

void app_main(void) {
    uart_init();
    at_send("AT+CMGF=1");
    at_send("AT+CNMI=2,1,0,0,0");
    char buf[UART_BUF];
    while (true) {
        int len = uart_read_bytes(MODEM_UART, (uint8_t*)buf, sizeof(buf)-1, pdMS_TO_TICKS(1000));
        if (len > 0) {
            buf[len] = '\0';
            ESP_LOGI(TAG, ">> %s", buf);
            char *cmti = strstr(buf, "+CMTI:");
                if (cmti) {
                    char *comma = strchr(cmti, ',');
                    if (comma) {
                        int idx = atoi(comma + 1);
                        ESP_LOGI(TAG, "Nuevo SMS en el índice %d", idx);
                        read_sms(idx);
                    }
                }
            }
        }
    }

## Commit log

2025-09-05 Agregar archivos de configuración y menús para el sistema de asistencia, incluyendo .gitignore, CMakeLists.txt, y archivos de texto y audio para las interacciones del usuario.
2025-09-05 Archivos de configuración de ESP
2025-09-05 Agregar archivo README con descripción de archivos de cabecera y configuración de secrets.h
2025-09-05 Agregar archivo main.c con la implementación del sistema de asistencia y manejo de alertas
2025-09-05 Agregar archivo audio.h con implementación de funciones para manejo de audio y montaje de tarjeta SD
2025-09-05 Agregar archivo modem.h con implementación de funciones para manejo de SMS, DTMF y tareas del módem
2025-09-05 Agregar archivo dtmf.h con implementación de funciones para manejo de DTMF y autorización de llamadas
2025-09-05 Agregar archivo sms.h con implementación de funciones para manejo de SMS y procesamiento de comandos
2025-09-05 Agregar archivo licence.md con la licencia del proyecto y condiciones de uso
2025-09-06 Agregar archivos STL para componentes del sistema de asistencia
    [Base_1.stl, Base_2.stl, Base_3.stl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]
2025-09-08 Agregar archivo README.md con la lista de materiales y detalles del proyecto Glauco Alert
2025-09-08 Agregar archivos STL para componentes del sistema de asistencia en sus correspondientes carpetas
    [Base_1.stl, Base_2.stl, Base_3.stl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]
